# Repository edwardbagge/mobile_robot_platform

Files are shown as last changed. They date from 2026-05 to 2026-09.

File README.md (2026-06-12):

# Mobile Robot Platform

This repository contains the hardware files, ESP32 firmware, low-level hardware tests, and ROS 2 workspace for a small differential-drive mobile robot.

## Repository Layout

- [firmware/](firmware): ESP32 firmware for the robot base.
- [hardware/](hardware): CAD and manufacturing files for the chassis, motor holders, lidar platform, and wheel hub adapters.
- [testing/](testing): manual non-ROS hardware bring-up tests for motors, encoders, serial communication, and Raspberry Pi integration.
- [ros2_ws/](ros2_ws): ROS 2 workspace with the current base, lidar, SLAM mapping, and navigation bring-up packages.

## Main Documentation

- [Hardware notes](hardware/README.md)
- [Hardware test notes](testing/README.md)
- [ROS 2 workspace notes](ros2_ws/README.md)

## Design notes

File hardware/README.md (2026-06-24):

# Hardware for the robot

Market hardware:

1) Slamtec RPLIDAR 360deg Laser Scanner Development Kit (A2M8) [product page](https://www.slamtec.com/en/lidar/a2)
3) Raspberry Pi 5 8GB
4) Geared 12V DC Motor (x2) [DFRobot product page](https://www.dfrobot.com/product-634.html)
5) [Adafruit HUZZAH32 ESP32 Feather](https://www.adafruit.com/product/3405) and [Adafruit HUZZAH32 ESP32 Feather guide](https://learn.adafruit.com/adafruit-huzzah32-esp32-feather)
6) [L298N motor driver](https://www.kouluelektroniikka.fi/tuote/ohjelmoitava-elektroniikka/moduulit/moottorinohjaimet/4615220/moottoriohjain-l298n)
7) [3S LiPo battery](https://www.akkuasiantuntija.fi/fi/artiklar/li-po-3s-111v-30c-2-200-mah-t-kontakti-vapex.html)
8) [T-plug to XT60 cable](https://www.akkuasiantuntija.fi/fi/artiklar/laddkabel-t-plug-hane-till-xt60-14awg-500mm.html)
9) Multiple Wago connectors, jumper wires, 3mm bolts; nuts; washers, double-sided tape, zip-ties, and other "prototyping"-stuff
10) Breadboard
11) Levelshifter (5V/3.3V)
12) [Mounting hub](https://partco.shop/product/axle-adapter-6-25-4mm-m3-4004) (part that is attached to 6mm motor-shaft)
13) [Caster wheel](https://partco.shop/product/ball-bearing-3-4-metal-4006)
14) Lego Technic 8069 rims and backwheels (or similar)
15) Fuse holder and 10A fuse
16) Electric switch
17) Buckconverter (Can endure over 5A)

Custom hardware:

1) Chassis
2) Elevated platform for Lidar
3) Holders for motors
4) Wheel adapters (connectors between motor mounting hubs and LEGO rims)

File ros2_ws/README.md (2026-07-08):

# ROS 2 Workspace Notes

This workspace contains the current ROS 2 software stack for the mobile robot platform. It includes the base controller nodes, the lidar bring-up, and the SLAM mapping workflow used to test autonomous mapping on the hardware. The stack is intended for ROS 2 Jazzy and assumes the robot is connected through the ESP32-based base controller and an RPLIDAR sensor.

At runtime, the system follows a simple information flow. A motion command is sent on /cmd_vel, the wheel velocity controller converts that command into wheel-level PWM values, the serial bridge forwards those values to the ESP32 firmware, and the firmware reports encoder feedback back to ROS 2 through the left and right encoder topics. The resulting motion estimate is published as /odom and as TF for use by mapping and navigation tools.

## Core packages

- `robot_base`: the main motion-control stack for the robot base.
- `robot_bringup`: launch files and configuration for the base, lidar, mapping, and navigation workflow.
- `rplidar_ros`: the ROS driver for the RPLIDAR sensor.
- `learning` and `experiments`: small test and learning packages used during development.

## Current base bring-up

The simplest way to start the base stack is to launch the base bring-up file, which starts the serial bridge, wheel velocity controller, and odometry node together.

Build the base package:

```bash
cd ~/Documents/mobile_robot_platform/ros2_ws
source /opt/ros/jazzy/setup.bash
colcon build --packages-select robot_base robot_bringup
source install/setup.bash
```

Launch the base stack:

```bash
ros2 launch robot_bringup base_odom.launch.py
```

This launch starts:
- `base_serial_bridge`
- `wheel_velocity_controller`
- `wheel_odometry`

Default parameters come from [src/robot_bringup/config/floor_safe_params.yaml](src/robot_bringup/config/floor_safe_params.yaml).

## SLAM mapping runbook

The bring-up stack provides the core data needed by SLAM mapping:

- `/cmd_vel` for velocity commands.
- `/odom` and `odom -> base_link` TF from wheel odometry.
- `/scan` from the RPLIDAR.
- `base_link -> laser` static TF from `robot_bringup`.

Install the required ROS packages once before using the mapping workflow:

```bash
sudo apt update
sudo apt install ros-jazzy-slam-toolbox ros-jazzy-nav2-map-server ros-jazzy-rviz2 ros-jazzy-teleop-twist-keyboard
sudo usermod -aG dialout $USER
```

Log out and back in after changing groups. For a clean start, use `mapping.launch.py` directly rather than launching the lower-level files separately.

Terminal 1: build and start mapping:

```bash
cd ~/Documents/mobile_robot_platform/ros2_ws
source /opt/ros/jazzy/setup.bash
colcon build --packages-select robot_base robot_bringup rplidar_ros
source install/setup.bash
mkdir -p maps
ls -l /dev/robot_base /dev/rplidar
ros2 launch robot_bringup mapping.launch.py
```

The robot uses stable device aliases for the serial connections:

```bash
/dev/robot_base
/dev/rplidar
```

These should be used consistently in the launch configuration. If either alias is missing, fix the hardware device setup before launching the stack.

Terminal 2: optional basic checks:

```bash
cd ~/Documents/mobile_robot_platform/ros2_ws
source install/setup.bash

ros2 topic echo /scan --once
ros2 topic hz /odom
ros2 run tf2_ros tf2_echo odom base_link
ros2 run tf2_ros tf2_echo base_link laser
```

Terminal 3: drive the robot slowly while mapping:

```bash
cd ~/Documents/mobile_robot_platform/ros2_ws
source install/setup.bash
ros2 run teleop_twist_keyboard teleop_twist_keyboard
```

Terminal 4: save the generated map:

```bash
cd ~/Documents/mobile_robot_platform/ros2_ws
source install/setup.bash
mkdir -p maps
ros2 run nav2_map_server map_saver_cli -f "$PWD/maps/floor1" --ros-args -p map_subscribe_transient_local:=true -p save_map_timeout:=30.0
```

Check that the map files were written:

```bash
cd ~/Documents/mobile_robot_platform/ros2_ws
ls -l maps
```

## Nav2 notes

Nav2 is separate from the SLAM mapping workflow. Install the Nav2 packages when you are ready to test navigation:

```bash
sudo apt update
sudo apt install ros-jazzy-navigation2 ros-jazzy-nav2-bringup
```

For a first Nav2 test while SLAM is still running:

```bash
ros2 launch robot_bringup nav2_navigation.launch.py
```

For Nav2 localization and navigation from a saved map:

```bash
ros2 launch robot_bringup nav2_map.launch.py map:=$HOME/Documents/mobile_robot_platform/ros2_ws/maps/floor1.yaml
```

Before relying on Nav2, add a robot-specific `nav2_params.yaml` for this platform. Tune robot radius or footprint, max velocity around `0.08-0.10 m/s`, acceleration limits, `/scan`, `/odom`, `base_link`, and costmap inflation. The current bring-up config publishes wheel odometry at `20.0 Hz` for Nav2.

## Base topic flow

The current command and feedback path is:

`/cmd_vel` -> `wheel_velocity_controller` -> `/wheel_pwm_cmd` -> `base_serial_bridge` -> ESP32

Encoder feedback returns as:

ESP32 -> `base_serial_bridge` -> `/left_encoder_ticks`, `/right_encoder_ticks`

Odometry output:

- `/odom`
- `odom -> base_link` TF by default

## Safety notes

The base stack includes two practical protections against bad encoder data:

- the controller stops publishing drive PWM if encoder feedback becomes stale,
- and both the controller and odometry logic reject implausible encoder jumps.

These protections are controlled mainly by the timeout and speed-related parameters in [src/robot_bringup/config/floor_safe_params.yaml](src/robot_bringup/config/floor_safe_params.yaml).

## Main files

- Base launch: [src/robot_bringup/launch/base_odom.launch.py](src/robot_bringup/launch/base_odom.launch.py)
- Lidar launch: [src/robot_bringup/launch/lidar.launch.py](src/robot_bringup/launch/lidar.launch.py)
- Robot launch: [src/robot_bringup/launch/robot.launch.py](src/robot_bringup/launch/robot.launch.py)
- SLAM launch: [src/robot_bringup/launch/slam.launch.py](src/robot_bringup/launch/slam.launch.py)
- Mapping launch: [src/robot_bringup/launch/mapping.launch.py](src/robot_bringup/launch/mapping.launch.py)
- Base and lidar params: [src/robot_bringup/config/floor_safe_params.yaml](src/robot_bringup/config/floor_safe_params.yaml)
- SLAM params: [src/robot_bringup/config/slam_params.yaml](src/robot_bringup/config/slam_params.yaml)
- Serial bridge: [src/robot_base/src/base_serial_bridge.cpp](src/robot_base/src/base_serial_bridge.cpp)
- Velocity controller: [src/robot_base/src/wheel_velocity_controller.cpp](src/robot_base/src/wheel_velocity_controller.cpp)
- Odometry: [src/robot_base/src/wheel_odometry.cpp](src/robot_base/src/wheel_odometry.cpp)

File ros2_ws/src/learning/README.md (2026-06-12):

# ROS 2 Learning Packages

This folder contains small ROS 2 learning and smoke-test packages. They are separate from the current robot packages and from the historical robot bring-up experiments.

- `simple_publisher`
- `simple_subscriber`

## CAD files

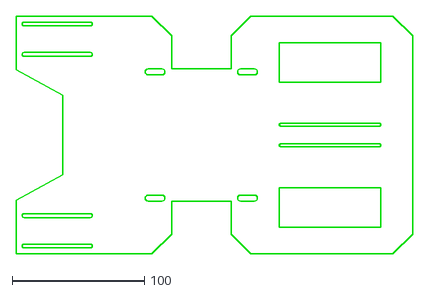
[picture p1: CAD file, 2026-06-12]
hardware/Chassis/chassis.dxf
300.0 x 180.0

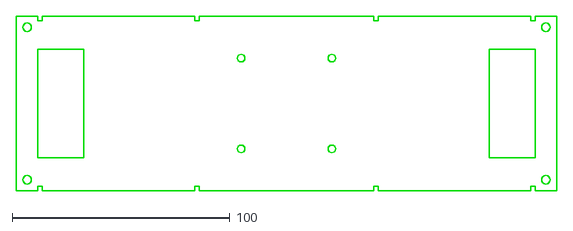
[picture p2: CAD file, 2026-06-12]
hardware/Lidar platform/lidar_platform - flat.dxf
248.0 x 80.0

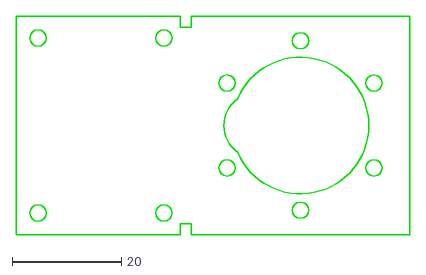
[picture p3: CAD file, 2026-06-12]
hardware/Motor holders/motor_holder.dxf
72.0 x 40.0

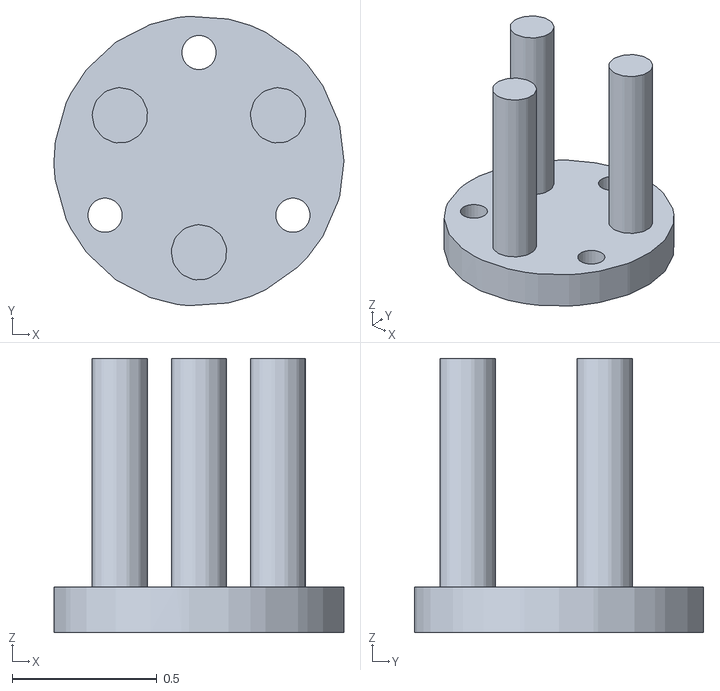
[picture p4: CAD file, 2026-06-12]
hardware/Wheel adapters/wheel_adapter_485.stl
1.00 x 0.998 x 0.945

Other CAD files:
hardware/Wheel adapters/wheel_adapter_484.stl
hardware/Chassis/chassis.psm
hardware/Lidar platform/lidar_platform - flat.psm
hardware/Lidar platform/lidar_platform.psm
hardware/Motor holders/motor_holder - flat.psm
hardware/Motor holders/motor_holder.psm

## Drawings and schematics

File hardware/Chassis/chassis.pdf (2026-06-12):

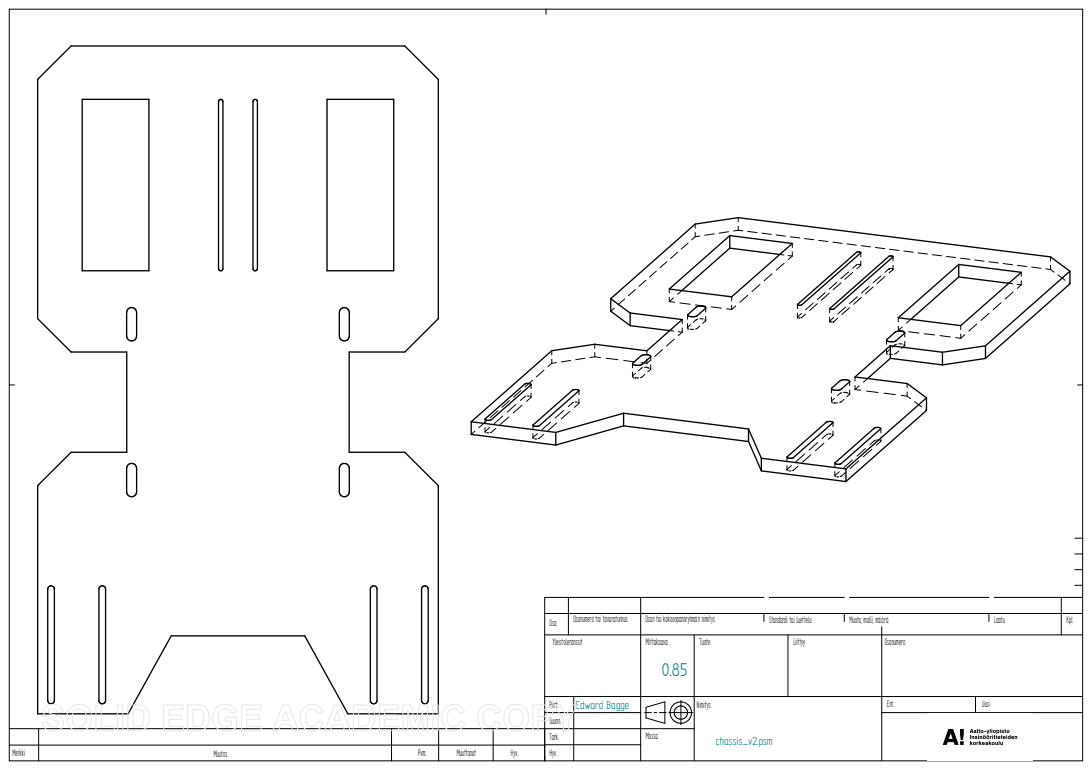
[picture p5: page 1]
Muoto, malli, määrä; Laatu; Kpl; Ent.; Uusi Edward Bagge

Osa | Osanumero tai tavaratunnus

Osan tai kokoonpanoryhmän nimitys

Standardi tai luettelo

Yleistoleranssit | Mittakaava 0.85 | Tuote | Liittyy | Osanumero

Piirt. | | | | | Nimitys chassis_v2.psm
Suunn.
Tark. | Massa

Merkki | Muutos | Pvm. | Muuttanut | Hyv. | Hyv.

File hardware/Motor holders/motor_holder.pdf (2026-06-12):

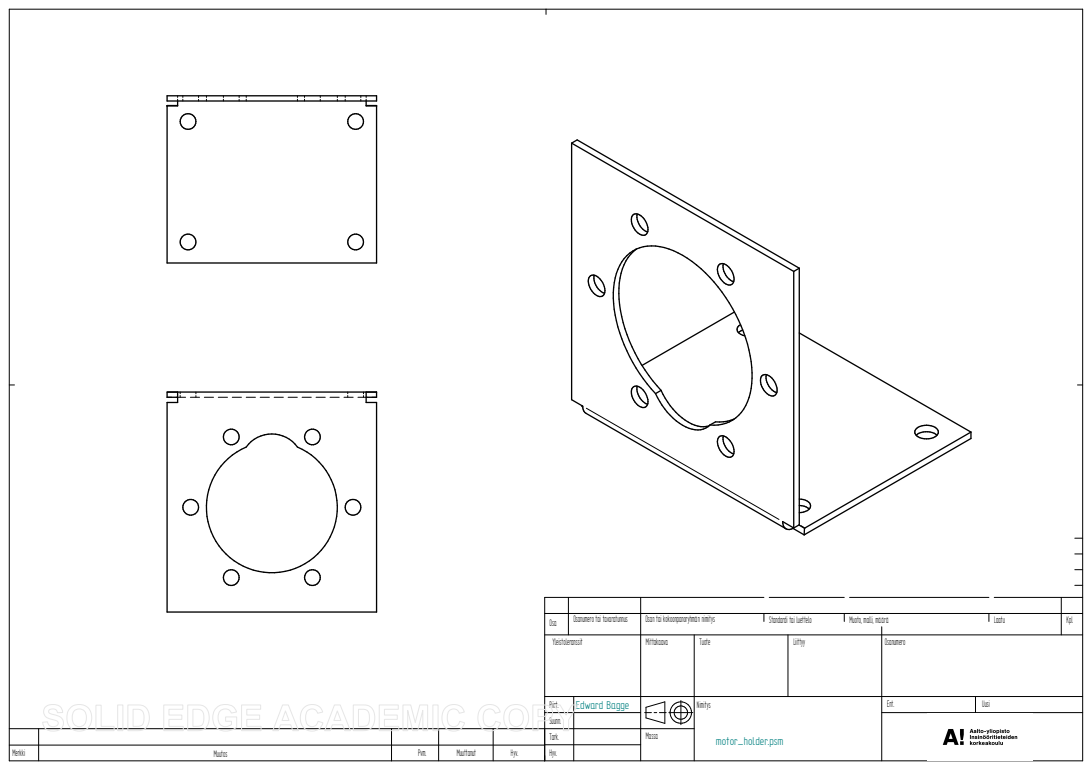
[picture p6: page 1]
Muoto, malli, määrä; Laatu; Kpl; Ent.; Uusi Edward Bagge

Osa | Osanumero tai tavaratunnus

Osan tai kokoonpanoryhmän nimitys

Standardi tai luettelo

Yleistoleranssit | Mittakaava | Tuote | Liittyy | Osanumero

Piirt. | | | | | Nimitys motor_holder.psm
Suunn.
Tark. | Massa

Merkki | Muutos | Pvm. | Muuttanut | Hyv. | Hyv.

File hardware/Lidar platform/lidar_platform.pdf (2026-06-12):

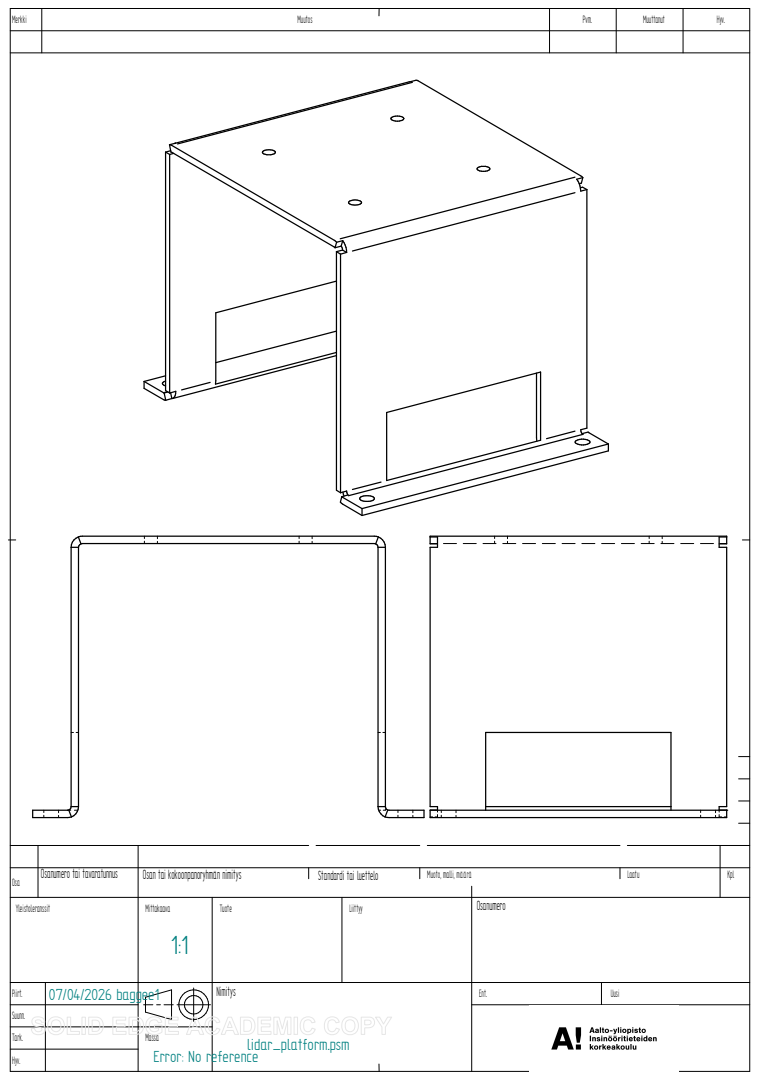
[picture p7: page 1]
Muoto, malli, määrä; Laatu; Kpl; Merkki; Muutos; Pvm.; Muuttanut; Hyv.; 07/04/2026 baggee1; Osanumero tai tavaratunnus; Osan tai kokoonpanoryhmän nimitys; Standardi tai luettelo

Osa
Yleistoleranssit | Mittakaava 1:1 | Tuote | Liittyy | Osanumero

Piirt. | | Error: No referencelidar_platform.psm | | | Nimitys | Ent. | Uusi

Suunn.
Tark. | | Massa
Hyv.

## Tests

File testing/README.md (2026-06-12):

# Hardware Bring-Up Tests

This folder contains manual hardware tests that run outside ROS 2. Use these tests to validate wiring, motor direction, encoder behavior, serial communication, and Raspberry Pi to ESP32 integration before relying on the ROS 2 stack.

ROS 2 milestone packages are kept under `ros2_ws/src/experiments/test_09` to `ros2_ws/src/experiments/test_13` so `colcon` can discover and build them. New automated ROS 2 tests for current packages should live inside the relevant ROS package, for example `ros2_ws/src/robot_base/test/`.

## Test Sequence

1. `01_encoder_diagnostic`
   - ESP32 encoder diagnostic for checking basic encoder signal behavior.

2. `02_motor_direction_test`
   - ESP32 motor direction test for confirming motor wiring and driver polarity.

3. `03_motor_encoder_combined_test`
   - ESP32 combined motor and encoder test for checking that commanded motion produces matching encoder feedback.

4. `04_quadrature_direction_test`
   - ESP32 quadrature direction test for validating encoder channel order and sign.

5. `05_speed_estimation_test`
   - ESP32 speed estimation test for checking tick-to-speed calculations.

6. `06_rpi_serial_command_test`
   - ESP32 serial command test for Raspberry Pi to ESP32 communication.

7. `07_rpi_motor_command_test`
   - ESP32 motor command test driven from the Raspberry Pi command path.

8. `08_rpi_motor_encoder_feedback_test`
   - ESP32 and Raspberry Pi test for motor commands plus encoder feedback over serial.

## Hardware Requirements

- Tests `01` to `05` are ESP32-side hardware tests.
- Tests `06` to `08` require the Raspberry Pi serial connection to the ESP32.
- Keep the robot lifted or otherwise safe during motor tests.

## Scope

Use this folder for manual low-level hardware bring-up tests. Use `ros2_ws/` for ROS 2 packages, ROS launch files, SLAM mapping, and ROS package tests.

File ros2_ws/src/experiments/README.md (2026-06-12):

# ROS 2 Experiments

This folder contains historical ROS 2 milestone packages from the robot bring-up process. They remain under `ros2_ws/src` so `colcon` can discover and build them, but they are not the current production robot stack.

- `test_09`: robot command serial bridge
- `test_10`: `/cmd_vel` serial bridge
- `test_11`: `/cmd_vel` bridge with encoder feedback
- `test_12`: wheel odometry from encoder ticks
- `test_13`: RPLIDAR bring-up and RViz verification

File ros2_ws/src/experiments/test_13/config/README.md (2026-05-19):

# test_13 config

This directory is reserved for future lidar test configuration such as:

1. RViz profiles.
2. Static transform defaults for `laser` to `base_link`.
3. Driver-specific parameter snapshots.

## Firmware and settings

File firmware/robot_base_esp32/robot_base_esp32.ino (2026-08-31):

// robot_base_esp32.ino
// ESP32 firmware for the differential-drive robot base.
//
// This sketch accepts motion commands from the Raspberry Pi over USB serial,
// drives the left and right motor H-bridges, and reports encoder feedback for
// closed-loop control and odometry.
//
// Serial protocol, 115200 baud:
//   M <left_pwm> <right_pwm>   signed PWM command, range -255..255
//   X                          brake/stop immediately
//   Z                          reset encoder counts
//   S                          print status
//

#include <ctype.h>
#include <stdint.h>
#include <stdio.h>
#include <stdlib.h>
#include <string.h>

// ---------- Motor pins ----------
const int RIGHT_IN1 = 13;
const int RIGHT_IN2 = 21;
const int RIGHT_EN  = 14;

const int LEFT_IN1  = 22;
const int LEFT_IN2  = 23;
const int LEFT_EN   = 32;

// ---------- Encoder pins ----------
const int LEFT_A  = 27;
const int LEFT_B  = 33;
const int RIGHT_A = 25;
const int RIGHT_B = 26;

// ---------- PWM settings ----------
const int PWM_FREQUENCY = 1000; // Motor PWM is switched at 1 kHz
const int PWM_RESOLUTION = 8;   // 8-bit PWM gives output values from 0 to 255
const int BRAKE_PWM = 255;      // PWM value used when the motors are actively braked
const int MAX_PWM = 255;        // Highest motor PWM value that can be commanded

// ---------- Timing ----------
const unsigned long COMMAND_TIMEOUT_MS = 300;  // Stop motors if no command is received after COMMAND_TIMEOUT_MS milliseconds
const unsigned long FEEDBACK_INTERVAL_MS = 50; // Send encoder feedback every FEEDBACK_INTERVAL_MS milliseconds
const size_t SERIAL_COMMAND_BUFFER_SIZE = 64;  // Maximum serial command length

// ---------- Encoder counters ----------

volatile int64_t leftTicks = 0;               // Accumulated encoder counts for the left side
volatile int64_t rightTicks = 0;              // Accumulated encoder counts for the right side
volatile int64_t leftInvalidTransitions = 0;  // Count encoder state changes that do not match a valid quadrature sequence
volatile int64_t rightInvalidTransitions = 0; // Same as above but for the right encoder
volatile uint8_t leftEncoderState = 0;        // Store the previous 2-bit encoder state for detecting direction and valid transitions
volatile uint8_t rightEncoderState = 0;       // Same as above but for the right encoder

int lastLeftPwm = 0;        // Most recent PWM command sent to left motor
int lastRightPwm = 0;       // most recent PWM command sent to right motor
bool commandActive = false; // Tells the program whether it currently has an active motion command

unsigned long lastCommandTime = 0;  // Store when the last command message occurred
unsigned long lastFeedbackTime = 0; // Store when the last feedback message occurred

char serialCommandBuffer[SERIAL_COMMAND_BUFFER_SIZE]; // Temporary storage for the text arriving over USB serial
size_t serialCommandLength = 0;                       // How many characters are currently stored
bool serialCommandOverflow = false;                   // Becomes true if an incoming command is too long for the buffer

struct EncoderSnapshot // Grouping these related values into one object
{
  int64_t leftTicks;
  int64_t rightTicks;
  int64_t leftInvalidTransitions;
  int64_t rightInvalidTransitions;
};

// ---------- Encoder interrupt handling ----------
// Read encoder channels A and B and combine them into a 2-bit state
uint8_t IRAM_ATTR readEncoderState(int pinA, int pinB)
{
  uint8_t a = digitalRead(pinA) ? 1 : 0;
  uint8_t b = digitalRead(pinB) ? 1 : 0;

  // A is the upper bit, and B is the lower bit
  return (a << 1) | b;
}

// Convert an encoder state change into a forward (+1), reverse (-1), or invalid/no-change (0) step
int8_t IRAM_ATTR decodeQuadratureTransition(uint8_t previousState, uint8_t currentState)
{
  // Combine the previous and current 2-bit states into one 4-bit value
  switch ((previousState << 2) | currentState)
  {
    case 0b0001:
    case 0b0111:
    case 0b1110:
    case 0b1000:
      return 1;

    case 0b0010:
    case 0b1011:
    case 0b1101:
    case 0b0100:
      return -1;

    default:
      return 0;
  }
}

// Handle a change in the left encoder signals
void IRAM_ATTR onLeftEncoder()
{
  uint8_t currentState = readEncoderState(LEFT_A, LEFT_B);
  int8_t step = decodeQuadratureTransition(leftEncoderState, currentState);

  if (step != 0) // Add or subtract one tick for a valid transition
  {
    leftTicks += step;
  }
  else if (currentState != leftEncoderState) // Count transitions that changed state but were not valid
  {
    leftInvalidTransitions++;
  }

  leftEncoderState = currentState; // Store the current state for the next transition
}

// Handle a change in the right encoder signals
void IRAM_ATTR onRightEncoder()
{
  uint8_t currentState = readEncoderState(RIGHT_A, RIGHT_B);
  int8_t step = decodeQuadratureTransition(rightEncoderState, currentState);

  if (step != 0) // Add or subtract one tick for a valid transition
  {
    rightTicks += step;
  }
  else if (currentState != rightEncoderState) // Count transitions that changed state but were not valid
  {
    rightInvalidTransitions++;
  }

  rightEncoderState = currentState; // Store the current state for the next transition
}

// ---------- Motor control ----------

int clampPwm(int pwm) // Limit the PWM command to the allowed range
{
  if (pwm > MAX_PWM)
  {
    return MAX_PWM;
  }
  if (pwm < -MAX_PWM)
  {
    return -MAX_PWM;
  }
  return pwm;
}

void setLeftMotor(int speedValue) // Set the left motor direction and PWM output
{
  speedValue = clampPwm(speedValue);

  if (speedValue > 0) // Forward direction
  {
    digitalWrite(LEFT_IN1, HIGH);
    digitalWrite(LEFT_IN2, LOW);
    ledcWrite(LEFT_EN, speedValue);
  }
  else if (speedValue < 0) // Reverse direction
  {
    digitalWrite(LEFT_IN1, LOW);
    digitalWrite(LEFT_IN2, HIGH);
    ledcWrite(LEFT_EN, -speedValue);
  }
  else // Stop motor (coast to a stop)
  {
    ledcWrite(LEFT_EN, 0);
    digitalWrite(LEFT_IN1, LOW);
    digitalWrite(LEFT_IN2, LOW);
  }
}

void setRightMotor(int speedValue) // Set the right motor direction and PWM output
{
  speedValue = clampPwm(speedValue);

  if (speedValue > 0) // Forward direction
  {
    digitalWrite(RIGHT_IN1, HIGH);
    digitalWrite(RIGHT_IN2, LOW);
    ledcWrite(RIGHT_EN, speedValue);
  }
  else if (speedValue < 0) // Reverse direction
  {
    digitalWrite(RIGHT_IN1, LOW);
    digitalWrite(RIGHT_IN2, HIGH);
    ledcWrite(RIGHT_EN, -speedValue);
  }
  else // Stop motor (coast to a stop)
  {
    ledcWrite(RIGHT_EN, 0);
    digitalWrite(RIGHT_IN1, LOW);
    digitalWrite(RIGHT_IN2, LOW);
  }
}

void brakeLeftMotor() // Apply active braking to the left motor
{
  digitalWrite(LEFT_IN1, HIGH);
  digitalWrite(LEFT_IN2, HIGH);
  ledcWrite(LEFT_EN, BRAKE_PWM);
}

void brakeRightMotor() // Apply active braking to the right motor
{
  digitalWrite(RIGHT_IN1, HIGH);
  digitalWrite(RIGHT_IN2, HIGH);
  ledcWrite(RIGHT_EN, BRAKE_PWM);
}

void releaseMotors() // Stop driving both motors without active braking
{
  setLeftMotor(0);
  setRightMotor(0);

  // Clear the stored motor command
  lastLeftPwm = 0;
  lastRightPwm = 0;
  commandActive = false;
}

void brakeMotors() // Actively brake both motors and clear the current command
{
  brakeLeftMotor();
  brakeRightMotor();
  lastLeftPwm = 0;
  lastRightPwm = 0;
  commandActive = false;

  Serial.println("Motors stopped with active brake.");
}

void applyMotorCommand(int leftPwm, int rightPwm) // Apply a new PWM command to both motors
{
  // Keep both commands within the allowed PWM range
  leftPwm = clampPwm(leftPwm);
  rightPwm = clampPwm(rightPwm);

  // Check whether the new command differs from the previous one
  bool commandChanged = (leftPwm != lastLeftPwm || rightPwm != lastRightPwm);

  setLeftMotor(leftPwm);
  setRightMotor(rightPwm);

  // Store the current command and update its timestamp
  lastLeftPwm = leftPwm;
  lastRightPwm = rightPwm;
  commandActive = (leftPwm != 0 || rightPwm != 0);
  lastCommandTime = millis();

  if (commandChanged) // Print only when the commanded PWM values change
  {
    Serial.print("CONTROL | LEFT pwm = ");
    Serial.print(leftPwm);
    Serial.print(" | RIGHT pwm = ");
    Serial.println(rightPwm);
  }
}

// ---------- Encoder helper functions ----------

EncoderSnapshot getEncoderSnapshot() // Copy all encoder counters without allowing interrupts to change them
{
  EncoderSnapshot snapshot;
  noInterrupts();
  snapshot.leftTicks = leftTicks;
  snapshot.rightTicks = rightTicks;
  snapshot.leftInvalidTransitions = leftInvalidTransitions;
  snapshot.rightInvalidTransitions = rightInvalidTransitions;
  interrupts();
  return snapshot;
}

void resetEncoderCounts() // Reset encoder counters and store the current encoder states
{
  noInterrupts();
  leftTicks = 0;
  rightTicks = 0;
  leftInvalidTransitions = 0;
  rightInvalidTransitions = 0;
  leftEncoderState = readEncoderState(LEFT_A, LEFT_B);
  rightEncoderState = readEncoderState(RIGHT_A, RIGHT_B);
  interrupts();

  Serial.println("Encoder counts reset.");
}

void printEncoderFeedback() // Print the current encoder counts and invalid-transition counts
{
  const EncoderSnapshot snapshot = getEncoderSnapshot();
  char feedbackLine[160];

  snprintf(
    feedbackLine,
    sizeof(feedbackLine),
    "FEEDBACK | LEFT ticks = %lld | RIGHT ticks = %lld | LEFT invalid = %lld | RIGHT invalid = %lld",
    static_cast<long long>(snapshot.leftTicks),
    static_cast<long long>(snapshot.rightTicks),
    static_cast<long long>(snapshot.leftInvalidTransitions),
    static_cast<long long>(snapshot.rightInvalidTransitions));

  Serial.println(feedbackLine);
}

void printStatus() // Print the current motor command, timing settings, and encoder feedback
{
  Serial.println();
  Serial.println("=== ROBOT BASE STATUS ===");
  Serial.print("LEFT pwm = ");
  Serial.println(lastLeftPwm);
  Serial.print("RIGHT pwm = ");
  Serial.println(lastRightPwm);
  Serial.print("Command active = ");
  Serial.println(commandActive ? "YES" : "NO");
  Serial.print("Command timeout ms = ");
  Serial.println(COMMAND_TIMEOUT_MS);
  Serial.print("Feedback interval ms = ");
  Serial.println(FEEDBACK_INTERVAL_MS);
  printEncoderFeedback();
  Serial.println();
}

// ---------- Serial command handler ----------

char *trimWhitespace(char *text) // Remove whitespace from the beginning and end of a command
{
  while (*text != '\0' && isspace(static_cast<unsigned char>(*text))) // Skip whitespace at the beginning
  {
    text++;
  }

  if (*text == '\0') // Return immediately if the string is empty
  {
    return text;
  }

  char *end = text + strlen(text) - 1; // Find the last character in the string
  
  while (end > text && isspace(static_cast<unsigned char>(*end))) // Remove whitespace from the end
  {
    *end = '\0';
    end--;
  }

  return text;
}

bool parseMotorCommand(const char *command, int &leftPwm, int &rightPwm) // Read the left and right PWM values from an M command
{
  if (command[0] != 'M' && command[0] != 'm') // Motor commands must begin with M
  {
    return false;
  }

  // Read the first number as the left motor PWM
  char *parseEnd = nullptr;
  long parsedLeft = strtol(command + 1, &parseEnd, 10);
  
  if (parseEnd == command + 1) // Fail if no number was found
  {
    return false;
  }

  // Read the second number as the right motor PWM
  char *rightStart = parseEnd;
  long parsedRight = strtol(rightStart, &parseEnd, 10);
  
  if (parseEnd == rightStart) // Fail if no second number was found
  {
    return false;
  }

  while (*parseEnd != '\0' && isspace(static_cast<unsigned char>(*parseEnd))) // Skip any whitespace after the second number
  {
    parseEnd++;
  }

  if (*parseEnd != '\0') // Reject the command if any other characters remain
  {
    return false;
  }

  leftPwm = static_cast<int>(parsedLeft);
  rightPwm = static_cast<int>(parsedRight);
  return true;
}

void handleCommand(const char *rawCommand) // Process one complete serial command
{
  // Copy the received command into a local buffer
  char commandBuffer[SERIAL_COMMAND_BUFFER_SIZE];
  strncpy(commandBuffer, rawCommand, sizeof(commandBuffer) - 1);
  commandBuffer[sizeof(commandBuffer) - 1] = '\0';

  char *command = trimWhitespace(commandBuffer); // Remove whitespace from the beginning and end

  if (*command == '\0') // Ignore empty commands
  {
    return;
  }

  char commandType = static_cast<char>(toupper(static_cast<unsigned char>(command[0]))); // Read the first character and convert it to uppercase
  
  if (commandType != 'M' && commandType != 'X' && commandType != 'Z' && commandType != 'S') // Ignore data that does not begin with a valid command letter
  {
    Serial.print("Ignored serial noise: ");
    Serial.println(command);
    return;
  }

  if (commandType == 'M' || commandType == 'm') // M: apply left and right motor PWM commands
  {
    int leftPwm = 0;
    int rightPwm = 0;

    if (parseMotorCommand(command, leftPwm, rightPwm))
    {
      applyMotorCommand(leftPwm, rightPwm);
    }
    else
    {
      Serial.print("Invalid motor command: ");
      Serial.println(command);
    }
  }  
  else if (commandType == 'X' || commandType == 'x') // X: actively brake both motors
  {
    brakeMotors();
    printEncoderFeedback();
  }
  else if (commandType == 'Z' || commandType == 'z') // Z: reset encoder counts
  {
    resetEncoderCounts();
  }
  else if (commandType == 'S' || commandType == 's') // S: print the current robot status
  {
    printStatus();
  }
  else
  {
    Serial.print("Unknown command: ");
    Serial.println(command);
  }
}

void processSerialInput() // Read serial input and build complete commands line by line
{
  while (Serial.available() > 0)
  {
    char incomingByte = static_cast<char>(Serial.read());

    if (incomingByte == '\r') // Ignore carriage-return characters
    {
      continue;
    }

    if (incomingByte == '\n') // A newline marks the end of a command
    {
      if (serialCommandOverflow)
      {
        Serial.println("Serial command too long. Buffer cleared.");
      }
      else if (serialCommandLength > 0)
      {
        // End the string and process the completed command
        serialCommandBuffer[serialCommandLength] = '\0';
        handleCommand(serialCommandBuffer);
      }

      // Prepare for the next command
      serialCommandLength = 0;
      serialCommandOverflow = false;
      continue;
    }

    if (serialCommandOverflow) // Ignore remaining characters if the command already overflowed
    {
      continue;
    }

    if (serialCommandLength >= SERIAL_COMMAND_BUFFER_SIZE - 1) // Reject commands that are too long for the buffer
    {
      serialCommandLength = 0;
      serialCommandOverflow = true;
      continue;
    }

    // Add the received character to the command buffer
    serialCommandBuffer[serialCommandLength] = incomingByte;
    serialCommandLength++;
  }
}

// ---------- Periodic checks ----------

void checkCommandTimeout() // Brake the motors if an active command has not been updated within the timeout
{
  if (commandActive && millis() - lastCommandTime >= COMMAND_TIMEOUT_MS)
  {
    Serial.println("Command timeout reached.");
    brakeMotors();
    printEncoderFeedback();
  }
}

void checkFeedbackPrint() // Send encoder feedback at the configured interval
{
  if (millis() - lastFeedbackTime >= FEEDBACK_INTERVAL_MS)
  {
    printEncoderFeedback();
    lastFeedbackTime = millis();
  }
}

// ---------- Setup ----------

void setup() // Initialize communication, motor control, encoders, and PWM
{
  // Start USB serial communication at 115200 baud
  Serial.begin(115200);
  delay(2000);

  // Configure H-bridge direction pins as outputs
  pinMode(LEFT_IN1, OUTPUT);
  pinMode(LEFT_IN2, OUTPUT);
  pinMode(RIGHT_IN1, OUTPUT);
  pinMode(RIGHT_IN2, OUTPUT);

  // Configure encoder channels as inputs
  pinMode(LEFT_A, INPUT);
  pinMode(LEFT_B, INPUT);
  pinMode(RIGHT_A, INPUT);
  pinMode(RIGHT_B, INPUT);

  // Store the encoder states at startup
  leftEncoderState = readEncoderState(LEFT_A, LEFT_B);
  rightEncoderState = readEncoderState(RIGHT_A, RIGHT_B);

  // Call the encoder interrupt functions whenever an encoder signal changes
  attachInterrupt(digitalPinToInterrupt(LEFT_A), onLeftEncoder, CHANGE);
  attachInterrupt(digitalPinToInterrupt(LEFT_B), onLeftEncoder, CHANGE);
  attachInterrupt(digitalPinToInterrupt(RIGHT_A), onRightEncoder, CHANGE);
  attachInterrupt(digitalPinToInterrupt(RIGHT_B), onRightEncoder, CHANGE);

  // Configure the PWM outputs used to control motor speed
  ledcAttach(LEFT_EN, PWM_FREQUENCY, PWM_RESOLUTION);
  ledcAttach(RIGHT_EN, PWM_FREQUENCY, PWM_RESOLUTION);

  // Start with the motors stopped and encoder counts at zero
  releaseMotors();
  resetEncoderCounts();

  Serial.println();
  Serial.println("=== ROBOT BASE ESP32 READY ===");
  Serial.println("Commands:");
  Serial.println("M <left_pwm> <right_pwm>");
  Serial.println("X = brake stop");
  Serial.println("Z = reset encoder counts");
  Serial.println("S = status");
  Serial.println();
}

void loop() // Continuously process commands, check the safety timeout, and send feedback
{
  processSerialInput();
  checkCommandTimeout();
  checkFeedbackPrint();
}

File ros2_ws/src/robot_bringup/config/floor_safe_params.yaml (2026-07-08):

# Parameters for the serial bridge node.
# This node connects ROS 2 to the ESP32 firmware over a serial port and forwards
# wheel commands and encoder feedback between the host computer and the robot.
base_serial_bridge:
  ros__parameters:
    serial_port: /dev/robot_base
    command_source: wheel_pwm_cmd
    command_rate_hz: 20.0
    command_timeout_s: 0.15
    wheel_base_m: 0.245
    max_wheel_speed_mps: 0.10
    max_pwm: 100
    min_pwm: 85
    left_pwm_scale: 1.0
    right_pwm_scale: 1.0
    active_brake_on_stop: true
    startup_delay_s: 2.5

# Parameters for the wheel velocity controller.
# These values determine how aggressively the robot tries to reach the desired
# wheel speed and how much feedback is required before the controller acts.
wheel_velocity_controller:
  ros__parameters:
    controller_rate_hz: 20.0
    command_timeout_s: 0.15
    encoder_timeout_s: 0.25
    wheel_base_m: 0.245
    wheel_radius_m: 0.041
    ticks_per_revolution: 2800.0
    max_wheel_speed_mps: 0.10
    max_tick_jump_scale: 3.0
    max_pwm: 100
    min_pwm: 85
    kp_pwm_per_mps: 240.0
    linear_deadband_mps: 0.005
    angular_deadband_rps: 0.01

# Parameters for the odometry estimator.
# These values define how encoder ticks are converted into robot motion and how
# the estimated pose is published for navigation and visualization.
wheel_odometry:
  ros__parameters:
    publish_rate_hz: 20.0
    ticks_per_revolution: 2800.0
    wheel_radius_m: 0.041
    wheel_base_m: 0.245
    max_wheel_speed_mps: 0.10
    max_tick_jump_scale: 3.0
    odom_frame_id: odom
    base_frame_id: base_link

# Parameters for the RPLIDAR driver node.
# These values configure the hardware connection and the scan output format.
rplidar_node:
  ros__parameters:
    serial_port: /dev/rplidar
    serial_baudrate: 115200
    frame_id: laser
    inverted: false
    angle_compensate: true
    scan_mode: ""

# Static transform from the robot base to the lidar frame.
# This defines the physical mounting position of the laser scanner on the robot.
laser_static_transform:
  ros__parameters:
    x: 0.050
    y: 0.000
    z: 0.135
    roll: 0.0
    pitch: 0.0
    yaw: 0.0
    parent_frame_id: base_link
    child_frame_id: laser

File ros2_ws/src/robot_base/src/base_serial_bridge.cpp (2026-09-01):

// base_serial_bridge.cpp
// ROS 2 bridge between robot motion commands and the ESP32.
//
// Receives motion commands from ROS 2, converts them to left/right motor PWM,
// sends them to the ESP32 over USB serial, and publishes encoder feedback.

// These are related to ROS 2
#include <geometry_msgs/msg/twist.hpp>
#include <rclcpp/rclcpp.hpp>
#include <std_msgs/msg/int32_multi_array.hpp>
#include <std_msgs/msg/int64.hpp>

// These are are Linux/system headers mainly used for the USB serial connection
#include <fcntl.h>
#include <termios.h>
#include <unistd.h>

// These are standard C++ headers
#include <algorithm>
#include <atomic>
#include <cerrno>
#include <chrono>
#include <cmath>
#include <cstring>
#include <functional>
#include <mutex>
#include <regex>
#include <sstream>
#include <string>
#include <thread>
#include <utility>

using namespace std::chrono_literals;

class BaseSerialBridgeNode : public rclcpp::Node // ROS 2 node that handles serial communication with the ESP32
{
public:
  // The constructor configures the node parameters, sets up the ROS 2
  // subscriptions and publishers, opens the serial connection to the ESP32,
  // starts a background reader thread for firmware feedback, and schedules a
  // periodic timer that repeatedly sends the latest command to the robot base.
  BaseSerialBridgeNode()
  : Node("base_serial_bridge"), running_(true)
  {
    serial_port_ = this->declare_parameter<std::string>("serial_port", "/dev/ttyUSB0");    // Serial device used for communication with the ESP32
    command_source_ = this->declare_parameter<std::string>("command_source", "cmd_vel");   // Select whether commands come from /cmd_vel or /wheel_pwm_cmd
    command_rate_hz_ = this->declare_parameter<double>("command_rate_hz", 20.0);           // Number of motor commands sent to the ESP32 per second
    command_timeout_s_ = this->declare_parameter<double>("command_timeout_s", 0.25);       // Stop the robot if no new command is received within this time
    wheel_base_m_ = this->declare_parameter<double>("wheel_base_m", 0.16);                 // Distance between the left and right wheels
    max_wheel_speed_mps_ = this->declare_parameter<double>("max_wheel_speed_mps", 0.25);   // Wheel speed corresponding to the maximum PWM command
    max_pwm_ = this->declare_parameter<int>("max_pwm", 80);                                // Maximum PWM value sent to the ESP32
    min_pwm_ = this->declare_parameter<int>("min_pwm", 0);                                 // Minimum non-zero PWM value
    left_pwm_scale_ = this->declare_parameter<double>("left_pwm_scale", 1.0);              // Scale factor applied to the left motor PWM
    right_pwm_scale_ = this->declare_parameter<double>("right_pwm_scale", 1.0);            // Scale factor applied to the right motor PWM
    linear_deadband_mps_ = this->declare_parameter<double>("linear_deadband_mps", 0.005);  // Treat very small linear velocity commands as zero
    angular_deadband_rps_ = this->declare_parameter<double>("angular_deadband_rps", 0.01); // Treat very small angular velocity commands as zero
    active_brake_on_stop_ = this->declare_parameter<bool>("active_brake_on_stop", true);   // Use active braking when the commanded motion is zero
    startup_delay_s_ = this->declare_parameter<double>("startup_delay_s", 2.5);            // Delay before communicating with the ESP32 after opening the serial port

    max_pwm_ = std::clamp(max_pwm_, 0, 255);                   // Keep PWM limits within the 8-bit range supported by the ESP32 firmware
    min_pwm_ = std::clamp(min_pwm_, 0, max_pwm_);              // Keep the minimum PWM between zero and the configured maximum

    // Limit motor-specific scaling factors to a reasonable range
    left_pwm_scale_ = std::clamp(left_pwm_scale_, 0.0, 2.0);
    right_pwm_scale_ = std::clamp(right_pwm_scale_, 0.0, 2.0);

    // These publishers expose the encoder feedback from the ESP32 as ROS 2
    // topics. Other nodes can subscribe to them for odometry or debugging.
    left_publisher_ = this->create_publisher<std_msgs::msg::Int64>("/left_encoder_ticks", 10);
    right_publisher_ = this->create_publisher<std_msgs::msg::Int64>("/right_encoder_ticks", 10);

    // The node can operate in two modes:
    // 1. Receive /cmd_vel (geometry_msgs/Twist) and convert it into wheel PWM.
    // 2. Receive /wheel_pwm_cmd (std_msgs/Int32MultiArray) when a higher-level
    //    controller already computed the left/right PWM values.
    if (command_source_ == "wheel_pwm_cmd") 
    {
      pwm_subscription_ = this->create_subscription<std_msgs::msg::Int32MultiArray>(
        "/wheel_pwm_cmd",
        10,
        std::bind(&BaseSerialBridgeNode::wheelPwmCallback, this, std::placeholders::_1));
    } 
    else 
    {
      command_source_ = "cmd_vel";
      cmd_vel_subscription_ = this->create_subscription<geometry_msgs::msg::Twist>(
        "/cmd_vel",
        10,
        std::bind(&BaseSerialBridgeNode::cmdVelCallback, this, std::placeholders::_1));
    }

    openSerialPort();      // Open the USB serial connection to the ESP32

    waitForEsp32Startup(); // Wait for the ESP32 to finish starting before communication begins

    read_thread_ = std::thread(&BaseSerialBridgeNode::readSerialLoop, this); // Start a separate thread that continuously reads serial feedback from the ESP32

    const auto period_s = 1.0 / std::max(command_rate_hz_, 1.0); // Calculate how long to wait between motor commands
    command_timer_ = this->create_wall_timer(
      std::chrono::duration_cast<std::chrono::nanoseconds>(
        std::chrono::duration<double>(period_s)),
      std::bind(&BaseSerialBridgeNode::sendCommandTimerCallback, this)); // Call sendCommandTimerCallback repeatedly at the configured command rate

    // Print the active configuration when the node starts
    RCLCPP_INFO(this->get_logger(), "Robot base serial bridge started.");
    RCLCPP_INFO(this->get_logger(), "Serial port: %s", serial_port_.c_str());
    RCLCPP_INFO(this->get_logger(), "command_source = %s", command_source_.c_str());
    RCLCPP_INFO(this->get_logger(), "command_rate_hz = %.2f", command_rate_hz_);
    RCLCPP_INFO(this->get_logger(), "command_timeout_s = %.2f", command_timeout_s_);
    RCLCPP_INFO(this->get_logger(), "wheel_base_m = %.3f", wheel_base_m_);
    RCLCPP_INFO(this->get_logger(), "max_wheel_speed_mps = %.3f", max_wheel_speed_mps_);
    RCLCPP_INFO(this->get_logger(), "max_pwm = %d", max_pwm_);
    RCLCPP_INFO(this->get_logger(), "min_pwm = %d", min_pwm_);
    RCLCPP_INFO(this->get_logger(), "left_pwm_scale = %.3f", left_pwm_scale_);
    RCLCPP_INFO(this->get_logger(), "right_pwm_scale = %.3f", right_pwm_scale_);
    RCLCPP_INFO(
      this->get_logger(),
      "active_brake_on_stop = %s",
      active_brake_on_stop_ ? "true" : "false");
    RCLCPP_INFO(this->get_logger(), "startup_delay_s = %.2f", startup_delay_s_);
  }
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

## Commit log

2026-04-11 Refactor motor speed variables and command handling
    Updated motor speed variables to be adjustable and improved command handling structure.
2026-04-12 Refactor encoder pin definitions in encoder_read_test
    Updated encoder pin assignments for left and right encoders.
2026-04-17 Add dual motor and encoder test for ESP32
2026-05-14 Add code for RPI that will test communication between it and ESP32
2026-05-18 Add test output log for serial bridge functionality
    Added output log for serial bridge test execution, including command feedback and motor encoder status.
2026-05-18 Add ROS2 commands for /cmd_vel topic publishing
    Added commands for publishing velocity to /cmd_vel topic using ROS2.
2026-05-18 Add output log for test_10 package execution
    This file contains the output log for the test_10 package, detailing the build process and the commands sent to the ESP32 for motor control, along with the feedback received during the tests.
2026-05-18 Changed some names etc. to avoid potential bugs
    [encoder_feedback_parser_test.cpp]
2026-05-18 Fixed test files and changed names to be more describing etc., same for functions and classes.
    [cmd_vel_encoder_bridge_test.cpp]
2026-05-29 Reverse motor direction logic for speed control
    [08_rpi_motor_encoder_feedback_test.ino]
2026-05-29 Modify motor test parameters and add braking
    Increased test speed and added brake functions for motors.
2026-05-29 Add 'a' command for automatic repeatability test
    Added option for automatic repeatability test in motor control commands.
2026-05-29 Enhance motor encoder feedback test functionality
    Updated the motor encoder feedback test to include additional run and brake tick calculations. Enhanced the test description for clarity.
2026-06-01 Enhance encoder feedback handling
    Added handling for invalid encoder transitions and improved encoder state management.
2026-06-03 Implement startup delay for ESP32 initialization
    Added startup delay parameter and wait function for ESP32 initialization.
2026-06-03 Fixed some stuff in the robot_base and robot_bringup thingies
    [base_serial_bridge.cpp, robot_base_esp32.ino]
2026-06-04 Add wheel_odometry executable with dependencies
2026-06-04 Clarify package description and add wheel odometry info
    Updated README to clarify package functionality and added details about wheel odometry.
2026-06-04 Update wheel_base_m parameters in YAML config
2026-06-04 Update wheel_base_m parameter in floor_safe_params.yaml
2026-06-04 Add PWM scale parameters for robot configuration
2026-06-04 Add PWM scaling parameters for left and right motors
2026-06-05 Implement PWM command source and active brake
    Added support for PWM command source and active brake feature.
2026-06-05 Add wheel_velocity_controller executable and dependencies
2026-06-05 Add wheel velocity controller parameters to launch
    Updated launch file to include controller parameters and modify descriptions.
2026-06-05 Change active brake on stop to false
2026-06-05 Enable active brake on stop in floor_safe_params.yaml
2026-06-08 Add laser static transform parameters
    Added static transform parameters for the laser frame.
2026-06-10 lidar testing
2026-06-19 Fixed names in hardware folder
    [wheel_adapter_484.stl, wheel_adapter_485.stl]
2026-09-01 Refactor comments and parameter descriptions in wheel_odometry
    Updated comments for clarity and consistency in the WheelOdometryNode class. Improved parameter descriptions for better understanding.
2026-09-02 Refactor wheel odometry code for clarity and comments
2026-09-08 Improve comments in wheel_velocity_controller.cpp
    Enhanced comments for better code clarity and understanding.
2026-11-05 Revise hardware README with detailed component info
    Updated the README to provide detailed descriptions of purchased components, custom-designed parts, and CAD files for the robot hardware.
